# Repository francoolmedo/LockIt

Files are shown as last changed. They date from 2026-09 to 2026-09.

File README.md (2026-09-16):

<div align="center">

# 🔐 LockIt

**Lockers inteligentes que se abren con un toque.**
Sin llaves, sin candados, sin fichas. Acercás tu celu al tag NFC y tu locker se abre.

*Córdoba, Argentina* · Producto físico + IoT + Web

</div>

---

## ¿Qué es LockIt?

LockIt es un sistema de **casilleros inteligentes** pensado para gimnasios, coworkings,
clubes, escuelas de danza/música, oficinas y aeropuertos. Cada locker se desbloquea
acercando el celular a un **tag NFC** pegado en la puerta, que abre una **webapp rápida**
y linda; la cerradura se libera sola. Un **sensor magnético** confirma si la puerta quedó
bien cerrada, y todos los lockers se comunican **en malla** por el WiFi del local para
mostrar, en conjunto, cuáles están libres y cuáles ocupados.

### El problema que resuelve
- **Llaves y fichas que se pierden**, se roban o hay que reponer.
- **No saber qué locker está libre** sin ir probando puerta por puerta.
- **Candados propios** que el local no controla ni puede liberar.
- Una experiencia **anticuada** en lugares que quieren verse modernos.

### La propuesta
- 📱 **Apertura con NFC**: acercás el celu, se abre. Cero fricción, cero app para instalar.
- 👀 **Estado visible**: dos líneas de producto —
  - **LockIt Clear** → puerta transparente (ves si hay algo adentro) + aro LED de estado.
  - **LockIt Glow** → puerta opaca + aro LED de color "fachero".
- 🕸️ **Red en malla**: los lockers se hablan entre sí y con un panel central.
- 🔒 **Confirmación real de cierre**: sensor de efecto Hall + imán detecta puerta cerrada.
- 🧰 **Control del local**: panel para asignar, liberar, ver ocupación y cobrar por uso.

---

## Estructura del repositorio

Este repo es un **monorepo** que contiene todo el proyecto: producto físico, electrónica,
firmware, software y go-to-market.

| Carpeta | Qué hay |
|---|---|
| [`docs/`](docs/) | Visión, **arquitectura técnica**, diseño industrial, fabricación en Córdoba, modelo de negocio y roadmap. |
| [`hardware/`](hardware/) | **BOM** (lista de materiales con costos), esquemático de conexiones y **firmware** del ESP32. |
| [`cad/`](cad/) | Modelo **CAD paramétrico** del locker (por código, exporta STEP/STL/DXF) y planos. |
| [`webapp/`](webapp/) | La **webapp** que se abre al escanear el NFC (prototipo funcional). |
| [`panel/`](panel/) | **Panel del local** (demo): ocupación en vivo, asignar/liberar/abrir. |
| [`landing/`](landing/) | **Landing page** animada para vender el producto. |
| [`marketing/`](marketing/) | Estrategia, copies de redes, guion de animación y outreach a empresas. |
| [`brand/`](brand/) | Identidad de marca (nombre, tono, paleta, dirección de logo). |

### Por dónde empezar a leer
1. [`docs/01-vision-y-producto.md`](docs/01-vision-y-producto.md) — qué construimos y para quién.
2. [`docs/02-arquitectura-tecnica.md`](docs/02-arquitectura-tecnica.md) — **cómo funciona todo el sistema**.
3. [`docs/06-roadmap.md`](docs/06-roadmap.md) — el camino de prototipo → piloto → producción.

---

## Estado del proyecto

🌱 **Etapa 1 — Fundación** (actual). Se define el producto, la arquitectura, el CAD, la
landing y el go-to-market. Todavía **no hay prototipo físico armado**.

Ver el detalle de etapas en [`docs/06-roadmap.md`](docs/06-roadmap.md).

---

## Líneas de producto

| | **LockIt Clear** | **LockIt Glow** |
|---|---|---|
| Puerta | Transparente (policarbonato/acrílico) | Opaca (melamina/chapa) |
| Estado | Se ve el interior + aro LED | Aro LED de color en la puerta |
| Ideal para | Gimnasios, clubes, escuelas | Oficinas, coworkings, uso premium |
| Costo relativo | Menor | Mayor (más electrónica) |

---

## Licencia

Ver [`LICENSE`](LICENSE).

> ⚠️ Este README y los documentos del repo son material de trabajo interno del proyecto.
> Precios, proveedores y especificaciones son estimaciones a validar en Córdoba.

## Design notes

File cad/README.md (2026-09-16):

# CAD — Modelo paramétrico del locker

CAD **por código** con [CadQuery](https://cadquery.readthedocs.io). Cambiás las medidas en
un archivo de parámetros y se regenera todo el modelo y los archivos para el taller.

## Requisitos

```bash
pip install cadquery        # probado con cadquery 2.8.0 / Python 3.11
```

## Uso

```bash
cd cad
python build.py             # exporta AMBAS variantes (clear + glow) a exports/
python build.py clear       # solo LockIt Clear
python build.py glow column # LockIt Glow + una columna de N módulos apilados
```

## Archivos

| Archivo | Qué es |
|---|---|
| `lockit_params.py` | **Todas las medidas** (mm). Única fuente de verdad. Editá acá. |
| `lockit_module.py` | Modelo: `build_body`, `build_door`, `build_assembly`, `build_column`, `door_profile_2d`. |
| `build.py` | Genera los archivos de fabricación en `exports/`. |
| `exports/` | Salida (STEP/STL/DXF/SVG). No se versiona el binario pesado; se regenera. |

## Qué genera (`exports/`)

Por cada variante (`clear`, `glow`):

| Salida | Para qué sirve |
|---|---|
| `..._gabinete.step` / `.stl` | Gabinete 3D. STEP = para el taller / otro CAD (Fusion, SolidWorks). STL = impresión 3D / preview. |
| `..._puerta.step` / `.stl` | Puerta 3D (ventana transparente en Clear o rebaje del aro LED en Glow). |
| `..._modulo.step` / `.stl` | **Ensamble completo** (gabinete + puerta + policarbonato en Clear), coloreado. |
| `..._puerta_corte2d.dxf` | **Plano de corte 2D** (contorno + calados) para láser/router CNC. Lo que va al taller. |
| `..._puerta_corte2d.svg` | Vista rápida del plano de corte. |
| `..._gabinete_iso.svg` | Vista previa isométrica del gabinete. |

## Medidas actuales (módulo de gimnasio)

- **Interior útil:** 300 × 400 × 450 mm (ancho × alto × prof) — entra mochila de gym, toalla, botella.
- **Exterior del módulo:** ~330 × 430 × 465 mm.
- **Columna de 4 puertas:** ~1.845 mm de alto (con base y tapa).
- **Material base:** panel de 15 mm (melamina resistente a humedad / chapa plegada equivalente).
- **Puerta:** 12 mm. Clear = policarbonato/acrílico con marco; Glow = opaca con rebaje para el aro LED.

> Ver el criterio de estas medidas y materiales en
> [`../docs/03-diseno-industrial.md`](../docs/03-diseno-industrial.md).

## Notas de diseño

- Es un modelo de **intención de diseño** para prototipo y cotización, no un plano de
  producción final. Espesores, holguras de puerta y herrajes se ajustan al material y a la
  máquina reales del taller en la Etapa 2.
- El alojamiento de cerradura + ESP32 está modelado como rebaje interno del lado opuesto a
  la bisagra (ver `_cut_lockbox`).
- La ventilación trasera evita olor/humedad (clave en gimnasios).
- Para pasar de melamina a **chapa plegada** se reusa la misma geometría: el `wall` pasa a
  representar el plegado y se generan los desarrollos de chapa (mejora futura del `build.py`).

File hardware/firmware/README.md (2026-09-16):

# Firmware · Nodo LockIt (ESP32)

Firmware del **nodo** de cada puerta. Un nodo puede correr en dos roles:
- **NODO**: controla su cerradura, lee el sensor de puerta, muestra estado, habla por ESP-NOW.
- **GATEWAY**: además, se conecta al WiFi del local y hace de puente con la nube (MQTT).

## Toolchain

Recomendado **PlatformIO** (VS Code) por manejo de librerías y multi-target. Alternativa:
Arduino IDE.

```ini
; platformio.ini (ejemplo)
[env:lockit_node]
platform = espressif32
board = esp32dev
framework = arduino
monitor_speed = 115200
lib_deps =
    ; fastled/FastLED               ; aro LED WS2812 (Clear y Glow)
    ; knolleary/PubSubClient        ; MQTT (solo gateway)
```

## Estructura

```
lockit_node/
├── config.h          # pines, rol, red, tiempos — TODO lo configurable
├── lockit_node.ino   # setup/loop + máquina de estados del locker
```

> Es un **esqueleto** para arrancar el prototipo: define la máquina de estados, el control de
> cerradura por pulso, la lectura del sensor Hall y los stubs de ESP-NOW/MQTT. La lógica de
> red real (emparejar peers ESP-NOW, protocolo de mensajes, MQTT topics) se completa en la
> Etapa 2 al armar el primer nodo físico.

## Máquina de estados del locker

```
LIBRE ──(reserva desde app)──> RESERVADO
RESERVADO ──(comando abrir)──> ABRIENDO ──(pulso cerradura)──> ABIERTO
ABIERTO ──(sensor: puerta cerrada)──> OCUPADO
OCUPADO ──(dueño abre de nuevo)──> ABIERTO
OCUPADO ──(liberar / fin sesión)──> LIBRE
```

## Protocolo ESP-NOW (borrador)

Mensajes cortos entre gateway y nodos:

| Tipo | Dirección | Payload |
|---|---|---|
| `OPEN` | gateway → nodo | id_locker |
| `STATE` | nodo → gateway | id_locker, estado, puerta(abierta/cerrada), rssi |
| `PING`/`PONG` | ambos | keepalive de malla |
| `ASSIGN` | gateway → nodo | id_locker ← sesión/usuario |

Se cifra con clave pre-compartida (PMK/LMK de ESP-NOW). Detalle de seguridad en
[`../../docs/02-arquitectura-tecnica.md`](../../docs/02-arquitectura-tecnica.md#8-seguridad-y-privacidad).

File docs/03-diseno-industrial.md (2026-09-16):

# 03 · Diseño Industrial

> Cómo se ve, se siente y se arma el locker. El objetivo: que **no parezca una caja de
> metal industrial**, sino un producto de diseño con carácter, y que a la vez sea
> **fabricable en Córdoba** y aguante el uso real de un gimnasio.

El modelo CAD paramétrico que materializa todo esto está en [`../cad/`](../cad/).

---

## Concepto de diseño

**"Confianza a la vista."** El locker comunica su estado sin que tengas que tocarlo: o ves
adentro (Clear) o te lo dice con luz (Glow). Líneas limpias, aristas suavemente redondeadas,
un punto de color (verde LockIt) como firma. Nada de bisagras a la vista ni candados
colgando.

- **Carácter, no ruido:** superficies mate, un solo acento de color, tipografía/numeración
  clara en cada puerta.
- **Modular y apilable:** se venden **columnas** de N puertas; el local arma su pared.
- **Antivandálico y anti-humedad:** pensado para vestuario de gym (sudor, agua, golpes).

---

## Dimensiones (módulo de gimnasio)

| Medida | Valor | Por qué |
|---|---|---|
| Interior útil | **300 × 400 × 450 mm** (an × al × prof) | Entra mochila de gym, toalla, botella, zapatillas. |
| Exterior módulo | ~330 × 430 × 465 mm | Con paredes de 15 mm. |
| Puertas por columna | 4 (config.) | Altura de columna cómoda (~1.85 m). |
| Altura de columna | ~1.845 mm | Todo alcanzable sin escalera. |
| Puerta | 12 mm | Rígida sin ser pesada. |

> Variante **Large** (mochilas grandes / cascos / aeropuerto): 350 × 550 × 500 mm, 3 puertas
> por columna. Definida en `cad/lockit_params.py` como `GYM_LARGE_CLEAR`.

---

## Materiales

### Estructura (gabinete)
| Opción | Pro | Contra | Uso |
|---|---|---|---|
| **Melamina 15 mm hidrófuga** | Barata, se corta/arma local, muchos colores | Menos resistente al agua extrema | ✅ Prototipo y gimnasios estándar |
| **Chapa plegada (acero pintado)** | Muy robusta, antivandálica | Más cara, requiere plegado/pintura | Ambientes duros / premium |
| **Compact/HPL fenólico** | Impermeable, ideal vestuario húmedo | El más caro | Spa, natatorios, premium |

### Puerta
- **Clear:** **policarbonato** (resistente a impacto, no astilla) o **acrílico** (más barato,
  se raya más). Recomendado policarbonato para uso intenso.
- **Glow:** melamina/MDF laminado o chapa, con **rebaje circular** para el aro LED.

### Herrajes
- Bisagras ocultas o de piano (según variante y presupuesto).
- Cerradura solenoide 12 V embutida (ver [hardware](../hardware/)).
- Patas/zócalo niveladores en la base de la columna.

---

## "Chiches" y detalles (lo que da carácter)

1. **Aro LED de estado** (Clear y Glow): verde = libre, ámbar = reservado, azul = ocupado,
   animación suave = abriendo. Se lee de lejos en todo el vestuario.
2. **Aro embutido a ras** (Glow): mismo aro sobre puerta opaca, con rebaje circular prolijo.
   Es el "wow", sin pantalla que envejezca.
3. **Numeración grande y legible** grabada/impresa en cada puerta.
4. **Rebaje de agarre** (sin manija que enganche ni se rompa) — modelado en el CAD.
5. **Ventilación trasera** discreta (ranuras) para que no junte olor/humedad.
6. **Zona NFC señalizada**: un círculo/ícono impreso donde apoyar el celu (UX física).
7. **Base con luz indirecta** opcional (línea LED al piso) para look premium.

---

## Ergonomía y accesibilidad

- Puertas y tags a altura alcanzable (evitar la fila más alta > 1.7 m para NFC).
- Al menos una columna con módulos a **altura accesible** (silla de ruedas) por instalación.
- Apertura que no invada el pasillo (puerta ~90°, o corredera en espacios chicos — variante futura).

---

## Acabados y color

- **Cuerpo:** grafito mate (firma LockIt) o blanco/gris para ambientes claros.
- **Acento:** verde LockIt en LED, detalles y numeración.
- **Personalización por cliente:** color de cuerpo y branding del gym en la puerta (upsell).

---

## De diseño a fabricación

El CAD paramétrico ([`../cad/`](../cad/)) exporta:
- **STEP/STL** del gabinete, puerta y ensamble → para el taller y para visualizar/renderizar.
- **DXF de corte 2D** de la puerta (contorno + calados) → directo a láser/router CNC.

El detalle de cómo mandarlo a fabricar en Córdoba y la plantilla de cotización están en
[`04-fabricacion-cordoba.md`](04-fabricacion-cordoba.md).

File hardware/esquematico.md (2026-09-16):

# Hardware · Esquemático de conexiones (nodo)

Diagrama de conexiones de **un nodo** (ESP32 + cerradura + sensor de puerta + indicador).
Pines de referencia para ESP32 WROOM-32 (ajustar en el firmware `config.h`).

## Diagrama de bloques

```mermaid
flowchart LR
    PSU[Fuente 12V] --> BUCK[Buck 12V→3.3V]
    PSU -->|12V| LOCKPWR[Cerradura 12V]
    BUCK -->|3.3V| ESP[ESP32]

    ESP -->|GPIO -> gate| MOSFET[MOSFET IRLZ44N]
    MOSFET -->|conmuta GND| LOCKPWR
    LOCKPWR -.diodo flyback.- MOSFET

    HALL[Sensor Hall A3144] -->|GPIO in| ESP
    MAG[Imán en la puerta] -.campo.- HALL

    ESP -->|GPIO data| RING[Aro LED WS2812 - Clear y Glow]

    NFC[Tag NFC pasivo en la puerta] -.lo lee el celular.- PHONE[📱]
```

> En la variante **base**, el NFC es un **tag pasivo** que lee el celular; el ESP32 **no**
> tiene lector. En la variante **Pro**, se agrega un lector PN532 por I2C/SPI al ESP32.

## Tabla de pines (referencia, ESP32 WROOM-32)

| Señal | Pin ESP32 | Notas |
|---|---|---|
| Cerradura (gate MOSFET) | GPIO 25 | Pulso 150–250 ms para abrir. Resistencia 100 Ω en gate, pulldown 10 kΩ. |
| Sensor Hall (puerta) | GPIO 34 (input only) | Pull-up; LOW/HIGH = cerrada/abierta (según imán). |
| Aro LED estado (Clear y Glow) | GPIO 26 | Data de WS2812 (aro direccionable). |
| Lector NFC PN532 (Pro) | GPIO 21/22 (I2C) o SPI | Solo variante Pro. |
| Alimentación lógica | 3V3 / GND | Desde buck converter. |

## Circuito de la cerradura (lo más delicado)

```
                +12V
                 │
              [Cerradura solenoide]
                 │
                 ├───────┐
                 │      ─┴─  Diodo flyback (1N4007) — cátodo a +12V
                 │      ───
                 │       │
              Drain      │
   GPIO25 ──[100Ω]── Gate  IRLZ44N (MOSFET N-channel, logic-level)
                    Source
                 │
                [10kΩ] pulldown a GND
                 │
                GND (común con ESP32)
```

**Reglas:**
1. **Masa común** entre 12 V y ESP32 (imprescindible).
2. **Diodo flyback** en antiparalelo a la cerradura (protege del pico inductivo al cortar).
3. MOSFET **logic-level** (IRLZ44N conmuta bien con 3.3 V; un IRF540 común NO).
4. Pulso corto para abrir; nunca dejar la cerradura energizada.

## Alimentación de una columna

```
Fuente 12V 5A ──┬── Nodo 1 (buck → ESP32 + cerradura)
                ├── Nodo 2
                ├── Nodo 3
                └── Nodo 4
```

Una fuente 12 V por columna alimenta todos los nodos (cada uno con su buck para la lógica).
Dimensionar la fuente por el **pico simultáneo** de cerraduras (peor caso: varias abriendo a
la vez → en la práctica se abren de a una, pero dejar margen).

## Seguridad eléctrica

- Fusible en la entrada de 12 V.
- Bornera con protección; cableado prolijo dentro de canaleta.
- En instalación final, certificar según normativa (ver
  [`../docs/04-fabricacion-cordoba.md`](../docs/04-fabricacion-cordoba.md)).

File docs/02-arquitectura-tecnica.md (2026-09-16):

# 02 · Arquitectura Técnica

> Este es el documento central de ingeniería. Describe **cómo funciona todo el sistema**,
> de la punta del celular al fierro de la cerradura. Cada decisión trae su alternativa y el
> porqué, para que sea discutible y quede registrado.

---

## 1. Vista general del sistema

LockIt tiene cuatro capas:

```mermaid
flowchart TB
    subgraph Usuario
        P[📱 Celular del usuario]
    end
    subgraph Local["Local (gimnasio, WiFi propio)"]
        subgraph Malla["Malla de lockers (ESP-NOW)"]
            N1[Nodo locker 1<br/>ESP32]
            N2[Nodo locker 2<br/>ESP32]
            N3[Nodo locker N<br/>ESP32]
        end
        GW[🛰️ Gateway<br/>ESP32 + WiFi del local]
        N1 --- GW
        N2 --- GW
        N3 --- GW
    end
    subgraph Nube["Nube (hosteado)"]
        API[API + Base de datos]
        WEB[🌐 WebApp NFC / PWA]
        PANEL[🖥️ Panel del local]
    end

    P -- "1. escanea tag NFC (URL)" --> WEB
    WEB -- "2. pide abrir locker X" --> API
    API -- "3. orden de apertura" --> GW
    GW -- "4. ESP-NOW: abrí X" --> N1
    N1 -- "5. libera cerradura + confirma con sensor" --> GW
    GW -- "6. estado real" --> API
    API --> PANEL
```

**Resumen del flujo feliz:** el usuario acerca el celu al tag NFC → se abre la webapp →
identifica el locker → pide apertura → la nube manda la orden al gateway → el gateway se la
pasa por malla al nodo del locker → el nodo libera la cerradura y confirma con el sensor
magnético que la puerta se abrió/cerró → el estado sube a la nube y se refleja en el panel.

---

## 2. El nodo del locker (hardware por puerta)

Cada puerta es un **nodo** autónomo con un ESP32. Detalle de componentes y costos en
[`hardware/BOM.md`](../hardware/BOM.md); conexiones en
[`hardware/esquematico.md`](../hardware/esquematico.md).

| Componente | Función | Notas |
|---|---|---|
| **ESP32** (WROOM-32 / C3) | Cerebro del nodo | WiFi + BLE + ESP-NOW. El C3 es más barato; el WROOM tiene más pines. |
| **Cerradura electromecánica 12 V** | Traba física | Solenoide (pestillo) o electroimán. Elegimos **solenoide tipo "cabinet lock"** (consume solo al abrir). |
| **Driver MOSFET / módulo relé** | Maneja los 12 V de la cerradura desde un pin de 3.3 V | MOSFET (ej. IRLZ44N) mejor que relé: silencioso, rápido, sin desgaste. Diodo flyback obligatorio. |
| **Sensor de efecto Hall + imán** | Confirma puerta **cerrada/abierta** | Imán en la puerta, sensor en el marco. Alternativa: reed switch (más barato, menos robusto). |
| **Lector NFC PN532** (opcional en el nodo) | Ver nota abajo sobre dónde va el NFC | En el modelo base el "NFC" es un **tag pasivo** en la puerta, no un lector. |
| **Indicador de estado** | **Aro LED direccionable WS2812** (Clear y Glow) | Verde=libre, ámbar=reservado, azul=ocupado; animación suave al abrir. |
| **Alimentación** | 12 V para cerradura, 3.3 V para ESP32 (buck converter) | Una fuente por columna alimenta a todos los nodos. |

### 2.1 ¿Lector NFC o tag NFC? — Decisión clave

Hay dos arquitecturas posibles para el "NFC en la puerta". Franco describió que el tag
**abre una webapp**, así que la arquitectura base es la **(A)**:

- **(A) Tag NFC pasivo (recomendada, base).** En la puerta va una **etiqueta NFC pasiva**
  (NTAG213/215, centavos) grabada con un registro **NDEF = una URL**, por ejemplo
  `https://app.lockit.ar/l/GYM01-014`. El celular la lee **nativamente** (sin app: Android e
  iOS abren URLs de tags NFC), se abre la PWA y el locker se identifica solo por la URL. **El
  nodo no necesita lector NFC** → mucho más barato y simple. La "inteligencia" de abrir está
  en la webapp + la nube + el ESP32.
- **(B) Lector NFC activo en el nodo.** El nodo lleva un **PN532** y el usuario apoya una
  tarjeta/llavero NFC propio. Sirve para **modo sin celular** (socios con credencial) o
  **modo offline** (abre sin internet validando la tarjeta localmente). Es más caro (~USD 4–8
  por puerta) pero da robustez.

**Plan:** arrancamos con (A) para el prototipo y el piloto. Dejamos (B) como **opción de
nodo "Pro"** para clientes que quieran credencial física o apertura offline garantizada.

---

## 3. Red: cómo se comunican los lockers

### 3.1 Topología elegida: malla ESP-NOW + un Gateway al WiFi

- Los nodos se hablan entre sí con **ESP-NOW** (protocolo de Espressif, sin router, bajo
  consumo, muy confiable en distancias cortas). Forman una **malla** liviana.
- **Un nodo hace de Gateway**: además de ESP-NOW, se conecta al **WiFi del local** y es el
  único que habla con la nube. Recibe órdenes de la API y las reparte por la malla; junta el
  estado de todos y lo sube.

```mermaid
flowchart LR
    Cloud[(☁️ Nube/API)]
    GW[🛰️ Gateway<br/>WiFi + ESP-NOW]
    Cloud <-->|WiFi del local| GW
    GW <-->|ESP-NOW| A[Nodo A]
    GW <-->|ESP-NOW| B[Nodo B]
    A <-->|ESP-NOW| C[Nodo C]
    B <-->|ESP-NOW| D[Nodo D]
```

**Por qué así (trade-offs):**

| Opción | Pro | Contra | Veredicto |
|---|---|---|---|
| **A) Todos al WiFi del local (estrella)** | Simple de programar | Depende 100% del WiFi del gym (que suele ser malo/saturado); satura el AP con N clientes | ❌ Frágil |
| **B) Malla ESP-NOW + 1 Gateway** ✅ | Solo 1 dispositivo usa el WiFi; malla robusta; funciona aunque el WiFi ande mal | Hay que manejar el ruteo simple y el rol de gateway | ✅ **Elegida** |
| C) painlessMesh (malla sobre WiFi) | Malla "real" con IP | Más pesado, más consumo, más inestable con muchos nodos | 🔸 Alternativa si ESP-NOW queda corto |
| D) LoRa / RS-485 cableado | Muy robusto/largo alcance | Cableado (RS-485) o licencias/costo (LoRa); over-engineering para un gym | 🔸 Solo para instalaciones grandes/distribuidas |

> **Regla práctica:** ESP-NOW anda excelente hasta decenas de nodos en el radio de un local.
> Si un cliente tiene cientos de puertas en varias salas, se ponen **varios gateways** por
> zona, cada uno con su sub-malla.

### 3.2 Redundancia del gateway
El rol de gateway se puede **elegir por software**: si el gateway se cae, otro nodo con
credenciales de WiFi asume el rol (elección por menor MAC, por ejemplo). Se documenta como
mejora post-piloto.

---

## 4. Flujo de desbloqueo, paso a paso

```mermaid
sequenceDiagram
    actor U as 📱 Usuario
    participant Tag as 🏷️ Tag NFC (puerta)
    participant Web as 🌐 WebApp (PWA)
    participant API as ☁️ API
    participant GW as 🛰️ Gateway
    participant Node as 🔒 Nodo locker

    U->>Tag: Acerca el celular
    Tag-->>U: URL https://app.lockit.ar/l/GYM01-014
    U->>Web: Abre la URL (navegador nativo)
    Web->>API: GET estado del locker 014 (+ token de sesión)
    API-->>Web: libre / ocupado / tuyo
    Note over Web,API: Validación "misma red" (ver §5)
    U->>Web: Toca "Abrir"
    Web->>API: POST abrir(GYM01-014)
    API->>GW: comando abrir(014) [MQTT/WebSocket]
    GW->>Node: ESP-NOW: abrir(014)
    Node->>Node: activa cerradura 200 ms
    Node->>Node: lee sensor Hall (¿puerta se abrió?)
    Node-->>GW: ack + estado real
    GW-->>API: estado(014) = abierto
    API-->>Web: ✅ abierto
    Web-->>U: Animación "¡Locker abierto!"
```

### Estados de un locker
`LIBRE → RESERVADO(tuyo) → ABIERTO → OCUPADO(cerrado con cosas) → LIBRE (al liberar)`

El **sensor Hall** es lo que distingue "cerrado" de "abierto" de verdad, y evita que el
sistema crea que está ocupado cuando la puerta quedó entornada.

---

## 5. Validación "misma red WiFi" — cómo lo hacemos bien

Franco pidió que la webapp **detecte que está en el mismo WiFi** que los lockers. Un
navegador **no puede leer el SSID del WiFi** por seguridad, así que lo resolvemos de forma
robusta. Opciones reales:

| Método | Cómo | Robustez | Uso |
|---|---|---|---|
| **URL firmada + estar presente físicamente** | El tag solo se puede escanear estando al lado del locker; la URL lleva el id + firma corta | Alta (requiere presencia física) | ✅ Base — el NFC ya prueba presencia |
| **Handshake local (mDNS/IP privada)** | La PWA intenta hablar con el gateway en la LAN (`http://lockit.local`) | Media (CORS/HTTPS mixto complica) | 🔸 Refuerzo opcional |
| **Token de sesión por tiempo** | Al escanear, la API abre una ventana de N minutos para ese locker/usuario | Alta | ✅ Base |
| **Chequeo de IP pública** | La API compara la IP pública del celu con la registrada del gateway del local | Media (WiFi del gym = misma IP saliente) | ✅ Refuerzo simple y efectivo |

**Diseño elegido (defensa en capas):**
1. El **tag NFC prueba presencia física** (estás parado frente al locker).
2. La **API abre una ventana de tiempo** (ej. 90 s) para operar ese locker.
3. La API **compara la IP pública** del celular con la del gateway del local → si coincide,
   está en la misma red del gym (refuerzo, no único). Si el celu está en datos móviles y no
   en el WiFi, se puede pedir un paso extra o igual permitir (configurable por local).

> Así no dependemos de que el navegador "vea el WiFi" (imposible), sino de pruebas reales:
> presencia física (NFC) + ventana temporal + coincidencia de red. Simple y difícil de abusar.

---

## 6. Modo degradado (sin internet)

El WiFi del gym **se va a caer** alguna vez. LockIt no puede dejar a nadie encerrado sin sus
cosas. Estrategias, de menor a mayor costo:

1. **Cache de sesiones en el gateway**: el gateway guarda las reservas activas; si se cae
   internet pero él sigue, resuelve aperturas localmente por un rato.
2. **Apertura por credencial física** (nodo "Pro" con lector NFC, opción B de §2.1):
   funciona 100% offline validando la tarjeta contra una lista local.
3. **Botón/llave maestra de emergencia** por columna para el staff (mecánico, siempre
   funciona aunque se corte la luz).
4. **Falla en seguro configurable**: por política del local, ante corte total la cerradura
   puede quedar **normalmente cerrada** (seguridad) o **liberarse** (que la gente saque sus
   cosas). Recomendado para gimnasios: mantener cerrado + llave maestra del staff.

---

## 7. Software: nube, webapp y panel

```mermaid
flowchart LR
    subgraph Front
      WEB[WebApp NFC - PWA]
      PANEL[Panel del local]
    end
    subgraph Back["Backend (hosteado)"]
      API[API REST/WebSocket]
      DB[(Base de datos)]
      MQ[Broker MQTT]
    end
    WEB <--> API
    PANEL <--> API
    API <--> DB
    API <--> MQ
    MQ <--> GW[Gateways de los locales]
```

- **WebApp NFC (PWA)** — [`../webapp/`](../webapp/): lo que ve el usuario al escanear.
  Rápida, sin instalación, con la marca. Prototipo mock ya incluido en el repo.
- **Panel del local**: ocupación en vivo, asignar/liberar, historial, cobros. (Etapa posterior.)
- **API + DB**: usuarios/sesiones, lockers, locales, eventos. Stack sugerido: Node/TS o
  Python (FastAPI) + Postgres. **A definir en Etapa 2.**
- **MQTT** entre la nube y los gateways: liviano, ideal para IoT, reconexión robusta.

---

## 8. Seguridad y privacidad

- **Tags NFC firmados**: la URL incluye una firma corta para que no se puedan clonar
  arbitrariamente lockers falsos. (NTAG con protección de escritura.)
- **Sesión por tiempo y por usuario**: un locker "tuyo" solo lo abrís vos dentro de la ventana.
- **Comunicación cifrada**: TLS entre PWA/panel y API; ESP-NOW con clave pre-compartida (PMK/LMK).
- **Mínimos datos personales**: se puede usar anónimo (solo id de sesión) o con cuenta según el local.
- **Antiabuso**: rate limiting en apertura; log de todos los eventos para auditoría del local.

---

## 9. Decisiones abiertas (a cerrar en Etapa 2)

- [ ] Cerradura definitiva: solenoide vs electroimán (probar consumo, ruido, robustez).
- [ ] ESP32 WROOM-32 vs C3 (pines vs costo) — decidir tras armar el primer nodo.
- [ ] Stack de backend (Node/TS vs Python/FastAPI) y hosting (Vercel/Fly/Railway/VPS).
- [ ] ¿Nodo base (solo tag) o nodo Pro (lector NFC) para el piloto? — depende del gym piloto.
- [ ] Sensor de puerta: Hall (robusto) vs reed switch (barato) — validar en prototipo.

Ver el plan de validación en [`06-roadmap.md`](06-roadmap.md).

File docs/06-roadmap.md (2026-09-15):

# 06 · Roadmap

> El camino de idea → producto → negocio, por etapas. Cada etapa tiene un objetivo claro y un
> "listo cuando…". Pensado para avanzar con poco capital y validar rápido.

---

## Etapa 0 · Fundación ✅ (actual)

**Objetivo:** definir el producto y dejar todo documentado y diseñado.

- [x] Visión, producto y dos líneas (Clear / Glow).
- [x] Arquitectura técnica completa (ESP32, malla, NFC, sensor, seguridad).
- [x] CAD paramétrico + archivos de fabricación (STEP/STL/DXF).
- [x] BOM, esquemático y esqueleto de firmware.
- [x] Identidad de marca (logo, paleta, tipografía, motion).
- [x] Landing con 3D en vivo + webapp NFC (mock).
- [ ] Estrategia de marketing y borradores de outreach (en curso).

**Listo cuando:** el repo cuenta la historia completa y se puede mostrar a un socio/proveedor.

---

## Etapa 1 · Prototipo funcional (1 nodo)

**Objetivo:** que **una puerta** abra de verdad con NFC.

- [ ] Comprar electrónica de 1 nodo ([BOM](../hardware/BOM.md)).
- [ ] Armar el circuito (cerradura + MOSFET + sensor Hall) en protoboard.
- [ ] Firmware: apertura por pulso + lectura de sensor + máquina de estados.
- [ ] Tag NFC → webapp → "abrir" (aunque sea contra un servidor local).
- [ ] Fabricar **1 gabinete** (melamina) para montar el nodo.

**Listo cuando:** acercás el celu, se abre la cerradura y el sensor confirma el cierre.
**Costo estimado:** bajo (~USD 30–60 electrónica + 1 gabinete).

---

## Etapa 2 · Columna piloto (4 puertas + red)

**Objetivo:** una **columna completa** con malla y panel.

- [ ] 4 nodos + 1 gateway hablando por ESP-NOW.
- [ ] Backend mínimo (API + estado + MQTT) hosteado.
- [ ] Webapp NFC real (asignación, sesión, abrir/liberar).
- [ ] Panel del local (ocupación en vivo, asignar/liberar).
- [ ] Modo degradado sin internet.
- [ ] Cotizar y fabricar la columna (melamina) en Córdoba.

**Listo cuando:** una columna de 4 puertas funciona sola, con panel y sin depender de una PC.

---

## Etapa 3 · Piloto en un gimnasio real

**Objetivo:** validar con usuarios reales y sacar el caso de éxito.

- [ ] Instalar 1–2 columnas en un gimnasio de Córdoba.
- [ ] Medir: tiempo de apertura, tasa de éxito, uso por puerta, incidencias.
- [ ] Iterar UX física (dónde va el tag, luz, etc.) y firmware.
- [ ] Juntar **testimonio + video real** para vender.

**Listo cuando:** el gimnasio lo usa a diario sin que tengas que estar ahí, y tenés métricas + video.

---

## Etapa 4 · Producto y primeras ventas

**Objetivo:** estandarizar y vender a más locales.

- [ ] Congelar diseño "v1" (estructura, electrónica, instalación).
- [ ] Cotizar **serie** (chapa o melamina) para bajar costo por puerta.
- [ ] Precio y contrato (hardware + suscripción, ver [negocio](05-modelo-negocio.md)).
- [ ] Vender a 3–5 gimnasios de Córdoba (outreach + boca a boca).
- [ ] Red mínima de instalación/soporte.

**Listo cuando:** hay clientes pagando y un proceso repetible de venta e instalación.

---

## Etapa 5 · Escala y nuevos segmentos

**Objetivo:** crecer más allá de gimnasios de Córdoba.

- [ ] Coworkings, clubes, escuelas de danza/música.
- [ ] Features premium (cobro por uso, reportes, integraciones).
- [ ] Variante aeropuerto/público (pago por uso, más seguridad).
- [ ] Expandir a otras ciudades / cadenas.

---

## Vista rápida

```mermaid
flowchart LR
    E0[0 · Fundación ✅] --> E1[1 · 1 nodo abre]
    E1 --> E2[2 · Columna + red + panel]
    E2 --> E3[3 · Piloto en gym real]
    E3 --> E4[4 · Producto + ventas]
    E4 --> E5[5 · Escala y segmentos]
```

> **Principio:** cada etapa cuesta poco y prueba algo. No fabricar 50 columnas antes de que
> **una** puerta funcione y **un** gimnasio la use.

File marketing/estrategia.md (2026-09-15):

# Marketing · Estrategia

> Cómo damos a conocer LockIt y conseguimos los primeros clientes, con poco presupuesto y
> foco en **gimnasios de Córdoba**. Usa la voz y la paleta de [`../brand/identidad.md`](../brand/identidad.md).

---

## Posicionamiento

> **LockIt es el casillero que se abre con un toque.** Sacá las llaves, los candados y las
> fichas del medio: tus clientes acercan el celu y listo, y vos controlás todo desde un panel.

- **Categoría:** casilleros inteligentes / control de accesos para lockers.
- **Diferenciales:** NFC **sin instalar app** · malla WiFi sin cablear datos · **soporte
  local** (Córdoba) · estética con carácter · dos líneas (Clear/Glow).
- **Contra qué competimos:** candados propios, llaves/fichas, y lockers electrónicos
  importados caros y sin soporte local.

---

## Público y mensaje

| Público | Qué le duele | Mensaje |
|---|---|---|
| **Dueño/gerente de gimnasio** (decisor) | Costo de llaves, robos, imagen, quejas | "Modernizá tus lockers, sacá las llaves del medio y diferenciate." |
| Socio del gym (usuario) | Perder la llave, no saber cuál está libre | "Tu locker, un toque. Sin llaves." |
| Coworking / oficina | Seguridad, prolijidad, estética | "Casilleros premium que se abren con el celu." |

---

## Embudo

```mermaid
flowchart LR
    A[Redes / boca a boca] --> B[Landing con 3D]
    B --> C[Demo / mensaje]
    C --> D[Piloto en el local]
    D --> E[Venta + suscripción]
    E --> F[Caso de éxito] --> A
```

- **Tope:** contenido en redes (el 3D y el "wow" del tap venden solos) + outreach directo.
- **Medio:** la [landing](../landing/) explica y genera el contacto ("Pedir demo").
- **Fondo:** demo/piloto → venta. El **caso de éxito** retroalimenta todo.

---

## Canales (priorizados para Córdoba)

1. **Instagram / Reels** — el producto es muy visual (tap → se abre, el 3D). Canal #1.
2. **Boca a boca / relaciones** — el primer gimnasio suele salir de un conocido.
3. **Outreach directo** (mail/WhatsApp) a gimnasios y locales — ver [outreach](outreach-empresas.md).
4. **LinkedIn** — para coworkings, oficinas y clientes B2B más formales.
5. **TikTok** — clips cortos del "wow" y del detrás de escena (fabricación en Córdoba).

---

## Contenido que funciona

- 🎬 **El tap mágico:** primer plano de acercar el celu y la puerta abriéndose.
- 🧩 **El 3D que se arma/desarma** (el de la landing) — muy shareable.
- 🏗️ **Detrás de escena:** fabricación en Córdoba, prototipo, "hecho acá".
- 📊 **Antes/después:** vestuario con candados vs. con LockIt.
- 🗣️ **Testimonio** del gimnasio piloto (cuando esté).

---

## Marca en todo

- Paleta Pulso (verde) + Señal (ámbar) + Grafito. Logo con la onda de pulso.
- Tipografía Archivo + IBM Plex. Motion = "el pulso".
- Todo consistente entre landing, redes, presentaciones y producto físico.
  Ver [`../brand/identidad.md`](../brand/identidad.md).

---

## Métricas

- Alcance/guardados de los reels (señal de "wow").
- Clicks a la landing y contactos "Pedir demo".
- Demos agendadas → pilotos → ventas.
- Costo por lead y por cliente.

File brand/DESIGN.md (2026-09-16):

---
# DESIGN.md · LockIt — sistema de diseño legible por agentes
# Formato inspirado en google-labs/design.md · reglas de impeccable + taste-skill
name: LockIt
style: Premium industrial cálido — oscuro, nítido, con carácter (no genérico)
colors:
  carbon:        "#100E0B"   # fondo base (dark) — casi negro CÁLIDO, nunca #000
  carbon-2:      "#15120E"
  panel:         "#1B1710"   # superficie (dark)
  panel-light:   "#FBF7F0"   # superficie (light)
  bg-light:      "#F4EFE7"   # fondo base (light) — crema cálido
  oro:           "#E7A23C"   # MARCA / acento primario
  oro-hi:        "#F2B255"   # hover
  oro-deep:      "#B07A1E"   # oro legible sobre claro (texto/borde)
  coral:         "#F0764F"   # acento secundario cálido
  cream:         "#F3EEE6"   # texto sobre carbón
  ink:           "#211A12"   # texto sobre claro
  ink-2:         "#5A4F41"
  ink-3:         "#8A7D6B"
  line:          "#2A2418"   # hairline (dark)
  line-light:    "#E1D7C6"   # hairline (light)
  # Semánticos — SOLO estado de producto, separados del acento de marca
  st-libre:      "#3BA776"
  st-ocupado:    "#F0764F"
  st-reservado:  "#74D3F0"
typography:
  display:  { family: "Newsreader",     weights: [400, 500, 600], use: "títulos serif editorial (dirección Warm)" }
  display_alt: { family: "Archivo",     weights: [700, 800, 900], use: "alternativa sans para variantes oscuras" }
  body:     { family: "IBM Plex Sans",  weights: [400, 500, 600] }
  mono:     { family: "IBM Plex Mono",  weights: [400, 500, 600], use: "datos, IDs (dashboard); usar poco" }
rounded: { sm: "9px", md: "12px", lg: "14px", pill: "999px" }   # crisp, NO rounded-2xl en todo
spacing: { xs: "6px", sm: "10px", md: "16px", lg: "24px", xl: "40px", xxl: "80px" }
elevation:
  flat:   "none — la mayoría de las superficies (borde, no sombra)"
  raised: "0 10px 30px rgba(20,14,6,.28) — SOLO lo que debe elevarse (1 nivel, no en todo)"
components:
  button-primary: { bg: oro, text: carbon, rounded: sm, weight: 600, shadow: flat, hover: "translateY(-2px)+oro-hi" }
  button-ghost:   { bg: transparent, border: line, text: ink, hover: "border/text → oro" }
  card:           { bg: panel, border: line, rounded: md, shadow: flat, note: "NO anidar cards dentro de cards" }
# Dials (taste-skill) — la personalidad de LockIt
dials:
  variant: "warm-editorial"       # DIRECCIÓN ACTIVA: crema cálido (Aesop) + serif Newsreader + oro muteado. Ground CLARO, no oscuro
  design_variance: 7              # 1 centrado/limpio … 10 asimétrico. 7 = editorial con tensión
  motion_intensity: 4             # 1 hover … 10 scroll/magnético. Sutil, con propósito
  visual_density: 3               # 1 espacioso … 10 dashboard denso. BAJO = mucho aire
  easing: "cubic-bezier(.4,0,.2,1)"   # NUNCA bounce/elastic (se siente viejo)
---

# Sistema de diseño · LockIt

> Leer antes de diseñar cualquier pieza (web, redes, panel, decks). El front matter de arriba
> son los **tokens** (fuente de verdad, no inventar). Abajo, el criterio.
>
> **Regla madre:** buen gusto = restricción + referencias reales + un gesto propio. Si tomaste
> una decisión "porque queda bien en general", es la mediana — y la mediana es el look de IA.

## Overview
LockIt es premium industrial cálido: base carbón (casi negro con temperatura), oro como único
protagonista, coral de apoyo. Nítido, con jerarquía fuerte, y **un** gesto memorable por pieza.
Referencia de altura: Linear (oscuro nítido), Aesop (editorial cálido), Teenage Engineering
(industrial premium).

## Colors
Neutros **siempre tintados** (carbón cálido, cremas), nunca `#000`/`#fff`/gris puro. Oro con
intención (CTA, un acento por sección). Coral escaso. Estados (libre/ocupado/reservado) son
semánticos y viven aparte del acento de marca. Nunca texto gris sobre fondo de color.

## Typography
Archivo para títulos (peso alto, tracking negativo), IBM Plex Sans para cuerpo, IBM Plex Mono
para datos. Jerarquía con **contraste real** de tamaño (no todo 16–20px). Un elemento manda.

## Layout
Grid/flex con `gap`. Varianza 6: buscar asimetría/tensión, no todo centrado. Aire generoso O
densidad elegida a propósito. Gutter lateral ≥16px. Mobile-first: mirar a ~400px y arreglar.

## Elevation & Shapes
Una sola sombra, sutil, **solo** donde algo se eleva — no en cada tarjeta (aplana la jerarquía).
Radios crisp (9–14px). Bordes/hairlines antes que sombras para separar.

## Do's & Don'ts (lista negra de AI-tells)
**Hacer:** tokens de arriba · referencia real antes que descripción · un gesto distintivo por
pieza · jerarquía fuerte · pasada final de reducción (sacar el 20% que sobra).

**Nunca (tells):**
- ❌ Fuentes genéricas: Inter, Roboto, Poppins, Montserrat, Space Grotesk, system defaults.
- ❌ `#000`/gris puro; texto gris sobre fondo de color (Impeccable). Tintar siempre.
- ❌ Gradiente violeta→azul en hero; glassmorphism.
- ❌ **Anidar cards dentro de cards**; envolver todo en tarjetas (Impeccable).
- ❌ Misma sombra + mismo radio en TODOS los bloques.
- ❌ Easing **bounce/elastic** (Impeccable) — usar el `easing` del front matter.
- ❌ Barrita/rail de color al costado de tarjetas.
- ❌ Todo centrado; sin asimetría.
- ❌ Grilla de 3 "features" ícono+título+parrafito ×3.
- ❌ Emojis como íconos/bullets → íconos = SVG de línea, un solo estilo.
- ❌ Negro puro + un único pop de color; combo crema+serif+terracota.
- ⚠️ **Nuestro propio riesgo:** abusar de eyebrows mono (`§01`) + grilla de puntos + marcas de
  esquina en TODO. Dosificar; si se repite en cada bloque, vuelve a ser plantilla.

## Vocabulario de trabajo (impeccable)
Al pedir cambios, usar verbos claros: `polish` (alinear al sistema), `critique` (jerarquía/
claridad), `quieter`/`bolder` (subir/bajar intensidad), `distill` (reducir), `animate`.

## Referencias — "Editorial Locker Room" (dirección elegida)
Dirección propia, a partir de los gimnasios premium del mundo. Diseñamos sacando el lenguaje
de ESTAS (Franco puede sumar/cambiar cuando quiera):
- **Equinox** — lujo editorial: blanco/negro confiado, acero ennegrecido, piedra natural,
  campañas audaces, tipografía grande. (el "cómo comunica" premium)
- **Third Space (Londres)** — oscuro, material, wellness premium; charcoal + latón.
- **Barry's** — drama/moodiness: luz cálida sobre oscuro (tomamos la atmósfera, no el rojo).
- **Vestuario de lujo (spa 5★)** — charcoal mate + **bronce** + madera + luz por capas →
  es literalmente nuestro carbón + oro. Ese es el material de LockIt.
- Athleisure elevado (Alo / Vuori) — calma cálida, mucho aire.

Traducción a la web: charcoal + bronce, tipografía oversized, **mucho whitespace**, filas
editoriales (no cajas), reglas finas, cromo mínimo. Cero look "instrumento técnico".
Más formato en `github.com/VoltAgent/awesome-design-md`.

## Checklist antes de publicar
- [ ] Tokens del front matter (nada inventado).
- [ ] Cero ítems de la lista negra.
- [ ] Salió de una referencia real, no del genérico.
- [ ] Un gesto distintivo; el resto quieto.
- [ ] Funciona a ancho de teléfono.
- [ ] Copy pasado por [`VOICE.md`](VOICE.md).
- [ ] Pregunta final: **"¿esto lo vi mil veces?"** → si sí, cambialo.

## Herramientas vivas (opcional, para instalar)
- `npx impeccable install` — detectores de anti-patterns en tiempo real (github.com/pbakaus/impeccable).
- taste-skill (github.com/leonxlnx/taste-skill) — skills por variante (soft/minimal/brutalist).
- google-labs/design.md — CLI para validar/exportar este archivo a Tailwind / W3C tokens.

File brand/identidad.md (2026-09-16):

# Identidad de marca · LockIt

> Sistema de identidad propio y ownable, diseñado para que LockIt **no parezca genérico ni
> hecho con plantilla**. Todo —colores, logo, tipografía, botones, animaciones— sale de una
> misma idea: **el pulso del toque**, el instante en que acercás el celu y el locker se abre.

---

## Idea central

**"El pulso."** LockIt captura ese microsegundo mágico: tap → onda → clic → abierto. Esa onda
que se expande es el ADN visual de la marca: aparece en el logo, en el LED que respira, en el
hover de los botones, en la animación del 3D. Nada es decoración: todo repite el gesto del
producto.

La piel de todo eso es **premium, oscura y cálida** — inspirada en el código visual de los
smart gyms de Córdoba (negro + oro, tipo Qivox): elegante, moderno y con carácter, lejos del
look "genérico de IA".

---

## Paleta (ownable)

Nombres propios para que el equipo hable el mismo idioma. Base carbón cálido + oro como
protagonista.

| Token | Nombre | Hex (oscuro / claro) | Uso |
|---|---|---|---|
| `--carbon` | **Carbón** | `#100E0B` / `#15120E` | Fondo principal / metal del locker. Casi negro **cálido** (no teal). |
| `--panel` | Panel | `#1C1811` / `#FBF7F0` | Tarjetas y superficies. |
| `--oro` | **Oro / Ámbar** ⭐ | `#E7A23C` | **Color de marca.** CTA, acentos, logo. Cálido, premium. |
| `--oro-hi` | Oro alto | `#F2B255` | Hover / brillo. |
| `--coral` | **Coral** | `#F0764F` | Segundo acento, amigable y trendy. Energía / estado "ocupado". |
| `--crema` | Crema | `#F0E6D6` | Detalle cálido / textos sobre carbón. |
| `--ink` | Tinta | `#F3EEE6` / `#211A12` | Texto (según tema). |

**Regla de oro:** el **Oro** es la estrella y se usa con intención (CTA, estado, un detalle
por sección). El **Coral** aporta calidez/energía como segundo acento. Nunca los dos gritando
a la vez; el resto es carbón y cremas.

### Semántica de estado (parte del producto y de la marca)
- 🟡 **Oro** = Libre / abierto / disponible (glow cálido que invita).
- 🟠 **Coral** = Ocupado / en proceso / energía.
- Luz general **cálida** (no fría): el producto se ve acogedor, no de laboratorio.

---

## Logo

Marca gráfica: un **candado premium** en oro con un **marco interior grabado** que evoca la
puertita del locker (el chiche que le da personalidad), y el ojo de cerradura calado.
Significado directo: **seguridad + se abre fácil**.

- Versión completa: símbolo + wordmark "LockIt" (Archivo 800, "It" en oro, tracking ajustado).
- Isotipo (ícono/app/favicon): el candado dentro de un cuadrado redondeado carbón. El calado
  del ojo de la cerradura usa el color del fondo (se lee como hueco real).
- Construcción y SVGs de referencia: [`logo.svg`](logo.svg) e [`isotipo.svg`](isotipo.svg).
- Área de protección: el alto del cuerpo del candado alrededor del logo. No deformar, no
  rotar, no cambiar los colores fuera de las variantes definidas.

### Variantes de color del logo
- Sobre carbón: símbolo en Oro, wordmark en Crema.
- Sobre claro: símbolo en Oro, wordmark en Carbón.
- Monocromo (grabado en la puerta física): un solo tono, sin relleno de estado.

---

## Tipografía

| Rol | Familia | Uso |
|---|---|---|
| **Display** | **Archivo** (700–800) | Títulos. Industrial, ancha, con carácter de señalética/producto. |
| **Texto** | **IBM Plex Sans** (400–600) | Cuerpo. Técnica, cálida, legible. |
| **Dato/UI** | **IBM Plex Mono** (400–600) | IDs de locker (`GYM01·014`), labels, estados, specs. El toque "máquina". |

Pareja elegida a propósito para **no** caer en el default de IA (Inter / Space Grotesk).
Titulares con `text-wrap: balance`, labels en mayúscula con `letter-spacing` amplio.

---

## Motion (lenguaje de animación)

Todo se mueve con el **gesto del pulso**: una onda que se expande con easing suave
(`cubic-bezier(.4,0,.2,1)`), nunca rebotes exagerados.

- **LED / estado:** respira (opacidad + halo) en loop lento.
- **Botones:** al hover, una onda de pulso sale desde el centro; leve `translateY(-1px)`.
- **3D showcase:** al scrollear, los lockers se **desarman y arman** (exploded view) y el
  modelo rota; el scroll es el "dial" de la animación.
- **Reveal:** las secciones entran desde un estado ya visible (nunca parten de opacidad 0
  esperando scroll para poder leerse).
- Respetar siempre `prefers-reduced-motion`: sin ondas ni auto-rotación, versión estática.

---

## Voz y tono

- **Directo y argentino, sin ser grasa.** "Tu locker, un toque." "Sacá las llaves del medio."
- Técnico cuando toca (specs), humano cuando vende (beneficios).
- Los controles dicen exactamente qué pasa: botón "Abrir mi locker" → "¡Abierto!".

---

## Aplicaciones

- **Web:** landing con 3D en vivo ([`../landing/`](../landing/)) y webapp NFC ([`../webapp/`](../webapp/)).
- **Producto físico:** numeración y logo monocromo grabado en la puerta; aro LED de color con la
  semántica de estado (verde libre · ámbar reservado · azul ocupado).
- **Redes:** ver [`../marketing/`](../marketing/) (los copies y el guion usan esta voz y paleta).

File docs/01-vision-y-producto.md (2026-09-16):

# 01 · Visión y Producto

## La visión

Convertir el casillero —un objeto tonto que no cambió en 50 años— en un **punto de
contacto inteligente** entre un local y sus clientes. LockIt vende dos cosas al mismo
tiempo:

1. A la **persona que lo usa**: una experiencia mágica y sin fricción (acercás el celu, se abre).
2. Al **local que lo compra**: control, datos de uso, una nueva fuente de ingresos y una
   imagen moderna, sin tener que manejar llaves ni reponer candados.

> **Frase ancla:** *"Tu locker, un toque."*

---

## Para quién (segmentos)

Mercado **ancla: gimnasios** (donde arrancamos). Después escalamos:

| Segmento | Dolor principal | Qué valora | Modelo de cobro típico |
|---|---|---|---|
| **Gimnasios** 🏋️ (ancla) | Candados propios, robos, "¿cuál está libre?" | Higiene, rapidez, imagen premium | Incluido en cuota / venta al gym |
| Coworkings / oficinas | Asignación de casillero fijo, seguridad | Estética sobria, control de accesos | Venta o alquiler mensual |
| Clubes / danza / música | Uso por clase/evento, rotación alta | Robustez, asignación rápida | Venta al club |
| Aeropuertos / público | Anonimato, seguridad, cobro por uso | Normativa, pago integrado | Pago por uso (self-service) |

La **decisión de foco** (gimnasios) fija: tamaño de módulo mediano, materiales que aguantan
humedad y uso intenso, y un pitch centrado en higiene + imagen + cero-llaves.

---

## Propuesta de valor

### Para el usuario final
- **Cero llaves, cero fichas, cero candado propio.** Nada que perder ni cargar.
- **Apertura en 2 segundos** acercando el celular al tag NFC (no hace falta instalar app).
- **Saber al toque qué locker está libre** (puerta transparente o indicador luminoso).
- **Seguridad**: solo vos (tu sesión) abrís tu locker durante tu uso.

### Para el local (quien compra)
- **Sin gestión de llaves** ni reposición de candados perdidos.
- **Panel de control**: ver ocupación en vivo, asignar, liberar remotamente, historial.
- **Higiene e imagen**: producto lindo, moderno, que se muestra.
- **Nuevo ingreso**: cobro por uso, alquiler premium de lockers grandes, o valor agregado a la cuota.
- **Instalación simple**: se conecta al WiFi que ya tienen; los módulos se hablan en malla.

---

## Las dos líneas de producto

Decidido con el equipo: lanzamos **dos variantes** que comparten el 90% de la estructura y
la electrónica, cambiando puerta e indicador.

### 🪟 LockIt Clear
- **Puerta transparente** de policarbonato (resistente a golpes) o acrílico (más económico).
- El estado "libre/ocupado" se ve **directo** (hay o no hay cosas) y se **refuerza con un
  LED** perimetral o un punto de luz (verde = libre, azul/rojo = ocupado).
- **Ventaja**: resuelve de una el problema de "¿está usado?" y es la variante **más barata**
  (menos electrónica por puerta).
- **Ideal**: gimnasios, clubes, escuelas — donde ver el interior es un plus de confianza.

### 🌗 LockIt Glow
- **Puerta opaca** (melamina, MDF laminado o chapa plegada) para **privacidad**.
- **Aro LED direccionable (WS2812)** embutido en la puerta que muestra el estado por color
  (verde libre · ámbar reservado · azul ocupado), con animación suave al abrir.
- **Ventaja**: más "tech", más premium, más privacidad.
- **Ideal**: oficinas, coworkings, uso premium.

> Ambas variantes usan el **mismo nodo electrónico** (ESP32 + NFC + cerradura + sensor de
> puerta). La diferencia de costo está en la puerta y en el aro LED (LED puntual vs aro WS2812).

---

## Principios de diseño de producto

1. **Cero fricción para el usuario**: no instalar app, no crear cuenta obligatoria, no esperar.
2. **A prueba de local real**: humedad, golpes, uso intenso, gente apurada, poco WiFi.
3. **Falla en seguro**: si se corta internet o luz, hay un modo de apertura garantizado
   (ver [arquitectura](02-arquitectura-tecnica.md#modo-degradado-sin-internet)).
4. **Modular y apilable**: se venden columnas de N puertas; el local arma su pared.
5. **Estético con carácter**: no parece una caja de metal industrial; parece un producto
   de diseño (ver [diseño industrial](03-diseno-industrial.md)).
6. **Fabricable en Córdoba**: materiales y procesos que consigue un taller local.

---

## Qué NO es LockIt (alcance)

- No es una cerradura para puertas de casa (es para casilleros de local comercial).
- No reemplaza la seguridad de una caja fuerte (es conveniencia + control, no alta seguridad
  bancaria).
- En la Etapa 1 **no** procesa pagos reales todavía (se diseña el flujo, se implementa después).

---

## Métricas de éxito (cómo sabremos que funciona)

- ⏱️ **Tiempo de apertura** < 3 s desde que acerca el celu.
- ✅ **Tasa de apertura exitosa** > 99% (que "se abra siempre").
- 🔁 **Confiabilidad del sensor de cierre** (falsos "abierto/cerrado" < 1%).
- 😍 **NPS del usuario** en el piloto del gimnasio.
- 💵 **Costo por puerta** por debajo del objetivo del [modelo de negocio](05-modelo-negocio.md).

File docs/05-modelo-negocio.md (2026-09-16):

# 05 · Modelo de Negocio

> Cómo gana plata LockIt. Números **estimados** para ordenar la conversación y validar que el
> negocio cierra. Ajustar con cotizaciones reales ([fabricación](04-fabricacion-cordoba.md)) y
> el mercado.

---

## Modelos de ingreso (se pueden combinar)

| Modelo | Cómo | Pro | Contra |
|---|---|---|---|
| **A. Venta directa** | El local compra las columnas (CAPEX) | Ingreso grande de una; simple | Ciclo de venta más lento; el local pone la plata |
| **B. Hardware + suscripción (SaaS)** | Vende el hardware + fee mensual por el panel/soporte/nube | Ingreso recurrente (MRR); pegajoso | Requiere sostener la plataforma |
| **C. Locker-as-a-Service** | LockIt instala gratis/subsidiado y cobra por uso o revenue share | Bajísima barrera para el local | Necesita capital para financiar el hardware |
| **D. Pago por uso (público)** | En aeropuertos/públicos, el usuario paga por usar | Ingreso directo del usuario final | Requiere pasarela de pago y alto tránsito |

**Recomendado para arrancar (gimnasios):** **B — Hardware + suscripción.** Vendés/instalás
las columnas y cobrás una **mensualidad por local** (panel, actualizaciones, soporte, garantía).
Da recurrencia y te diferencia de un simple mueble.

---

## Estructura de precios (propuesta inicial, ARS/USD — validar)

### Hardware (una vez)
- **Columna de 4 puertas (Clear):** precio de venta objetivo **USD 700 – 1.000** por columna
  (según costo real ~USD 330–540 → margen bruto ~45–55%).
- **Columna Glow (aro LED):** +USD 60–120 por la puerta opaca y el aro LED direccionable.
- **Instalación y setup:** por proyecto (según cantidad de columnas).

### Suscripción (recurrente, por local)
- **Plan base:** **USD 20 – 40 / mes por local** (panel, soporte, updates).
- Escala por cantidad de puertas / features (asignación avanzada, reportes, cobro por uso).

### Ejemplo de un gimnasio tipo
- Compra 5 columnas Clear (20 puertas): 5 × USD 850 = **USD 4.250** (hardware).
- Suscripción: **USD 30 / mes** → **USD 360 / año** recurrente.

---

## Unit economics (por puerta, estimado)

| Concepto | USD |
|---|---|
| Costo hardware por puerta (estructura + electrónica, a escala) | 90 – 135 |
| Precio de venta por puerta (columna/4) | 175 – 250 |
| **Margen bruto por puerta** | **~45 – 55%** |
| + Suscripción anual prorrateada por puerta | ~4 – 8 / año recurrente |

> A escala (series de 25–50 columnas), el costo por puerta baja y el margen mejora. La
> **suscripción** es lo que convierte a LockIt de "vender muebles" a "negocio recurrente".

---

## Costos del negocio (además del hardware)

- **Desarrollo** (firmware, webapp, panel, nube) — mayor al principio, luego mantenimiento.
- **Hosting/nube** (API, MQTT, base de datos) — bajo por local, escala con el uso.
- **Soporte y garantía** — clave para retención; cubierto por la suscripción.
- **Ventas y marketing** — ver [marketing](../marketing/).
- **Stock/producción** — capital de trabajo para fabricar series.

---

## Estrategia de entrada (go-to-market)

1. **1 gimnasio piloto en Córdoba** (idealmente con relación previa): instalar 1–2 columnas,
   medir uso, juntar testimonio y video real.
2. **Caso de éxito** → usarlo para vender a otros gimnasios de Córdoba (boca a boca + outreach).
3. **Estandarizar** el producto y la instalación para bajar costos y tiempos.
4. **Escalar por segmento**: gimnasios → cadenas de gym → coworkings → clubes → aeropuertos.

---

## Métricas del negocio a seguir

- **CAC** (costo de adquirir un local) vs **LTV** (hardware + suscripción en el tiempo).
- **MRR** (ingreso recurrente mensual) y churn de locales.
- **Margen bruto por columna** real (post-cotizaciones).
- **Uso por puerta/día** (prueba de valor y base para pago por uso).

---

## Riesgos y mitigación

| Riesgo | Mitigación |
|---|---|
| Costo de hardware alto (Argentina/importación) | Compra por volumen, componentes locales, diseño frugal |
| Ciclo de venta lento a locales | Modelo as-a-service / financiación; empezar por conocidos |
| Competencia (lockers electrónicos importados) | Diferenciación: NFC sin app + malla + soporte local + estética |
| Dependencia del WiFi del local | Malla ESP-NOW + modo degradado ([arquitectura](02-arquitectura-tecnica.md#6-modo-degradado-sin-internet)) |
| Soporte técnico a distancia | Panel con diagnóstico remoto; red de instaladores |

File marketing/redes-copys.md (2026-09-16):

# Marketing · Copies de redes + guion de animación

> Contenido listo para publicar. **Vos publicás** desde tus cuentas — yo no tengo acceso a
> tus redes. Usá la voz de [`../brand/identidad.md`](../brand/identidad.md): directa, argentina,
> con carácter.

---

## Bio / presentación

**Instagram bio:**
> 🔐 LockIt — Casilleros inteligentes que se abren con un toque.
> Sin llaves. Sin candados. NFC + panel para tu local. 📍 Córdoba, AR
> 👇 Cómo funciona

**Una línea (elevator):**
> LockIt convierte cualquier casillero en uno inteligente: tus clientes lo abren acercando el
> celu, y vos lo controlás todo desde un panel.

---

## Post de lanzamiento (carrusel)

1. **Portada:** "Tu locker, un toque." (con el 3D del locker)
2. "Sin llaves. Sin candados. Sin fichas."
3. "Acercás el celu al tag NFC → se abre. Sin instalar ninguna app."
4. "¿Libre u ocupado? Se ve de una: puerta transparente o indicador luminoso."
5. "Los lockers se hablan entre sí por WiFi y te muestran todo en un panel."
6. "Dos líneas: Clear (transparente) y Glow (opaca + aro LED de color)."
7. **Cierre/CTA:** "Hecho en Córdoba 🇦🇷. ¿Tenés un gym o local? Escribinos. → @lockit"

**Caption:**
> El casillero no cambió en 50 años. Nosotros lo estamos cambiando. 🔐
> LockIt: acercás el celu, se abre. Cero llaves, cero candados, cero fichas — y vos controlás
> todo desde un panel.
> Estamos arrancando en Córdoba y buscamos gimnasios para el piloto. ¿Se te ocurre uno? 👇
> #Córdoba #Gimnasios #Tecnología #NFC #Emprender #HechoEnCórdoba

---

## Guion de Reel #1 — "El tap mágico" (15–20 s)

| Tiempo | Imagen | Texto en pantalla | Audio |
|---|---|---|---|
| 0–2 s | Persona llega al vestuario con la mochila | "Perdiste la llave otra vez." | música in |
| 2–5 s | Primer plano: acerca el celu al tag NFC | "¿Y si no hubiera llave?" | *tap* |
| 5–8 s | La puerta se abre sola (LED verde → ) | "Un toque. Se abre." | *click* |
| 8–12 s | Guarda las cosas, cierra, LED ámbar | "Se traba solo. Vos, tranqui." | beat |
| 12–16 s | El 3D del locker girando (de la landing) | "LockIt · casilleros inteligentes" | drop |
| 16–20 s | Logo + CTA | "Córdoba 🇦🇷 · Escribinos" | outro |

> **Tip:** el clip del **3D que se arma/desarma** de la landing es oro para el cierre.

---

## Guion de Reel #2 — "Detrás de escena / hecho en Córdoba" (20–30 s)

- Del CAD en pantalla → al corte en el taller → al gabinete armado → al locker funcionando.
- Texto: "De un plano… a un producto. Diseñado y fabricado en Córdoba."
- Cierre: "LockIt. Tu locker, un toque."

---

## Ideas de contenido (calendario simple)

| Semana | Post | Reel |
|---|---|---|
| 1 | Carrusel de lanzamiento | Reel #1 "El tap mágico" |
| 2 | "Clear vs Glow" (comparativa) | Detrás de escena (CAD → taller) |
| 3 | "3 problemas del casillero de siempre" | El 3D girando + specs |
| 4 | Encuesta: "¿Qué locker tenés en tu gym?" | Testimonio / avance del piloto |

---

## Hashtags base

`#LockIt #Córdoba #HechoEnCórdoba #Gimnasios #Fitness #NFC #Tecnología #Emprender #Coworking #Innovación`

---

## Kit de placas (archivos de diseño)

Las placas están diseñadas en [`redes/`](redes/) como un **canvas de Claude Design**
(`kit-redes-lockit.html`) — se abre, se edita a mano y se **exporta cada placa a PNG**.

| Artboard | Uso | Medida |
|---|---|---|
| `Perfil.dc.html` | Foto de perfil | 1080×1080 |
| `Main.dc.html` | Carrusel 1 · Hook "Tu locker, un toque" | 1080×1080 |
| `Problema.dc.html` | Carrusel 2 · El problema | 1080×1080 |
| `ComoFunciona.dc.html` | Carrusel 3 · Acercás, se abre | 1080×1080 |
| `Lineas.dc.html` | Carrusel 4 · Clear vs Glow | 1080×1080 |
| `ParaQuien.dc.html` | Carrusel 5 · Segmentos (gimnasios ancla) | 1080×1080 |
| `CTA.dc.html` | Carrusel 6 · CTA | 1080×1080 |
| `Testimonios.dc.html` | Testimonios (plantilla con placeholders) | 1080×1080 |
| `Precios.dc.html` | Precios (planes, montos placeholder) | 1080×1080 |
| `Panel.dc.html` | Pantallazo del panel del local | 1080×1080 |
| `StoryAnuncio.dc.html` | Story de anuncio | 1080×1920 |
| `reel.html` | Reel animado (grabar en pantalla) | 9:16 |

> Reemplazá `@lockit` por tu handle real cuando lo tengas. El reel se **graba en pantalla**
> (loop de ~12 s) y se sube como reel/short.

### Caption lista para el carrusel de lanzamiento
> El casillero no cambió en 50 años. Nosotros lo estamos cambiando. 🔐
> **LockIt**: acercás el celu y se abre. Cero llaves, cero candados, cero fichas — y el local
> controla todo desde un panel.
> Estamos arrancando en Córdoba y buscamos gimnasios para el piloto. ¿Conocés uno? Etiquetalo 👇
> `#Córdoba #Gimnasios #Fitness #Tecnología #NFC #Emprender #HechoEnCórdoba`

### Caption para el reel
> Sin llaves. Sin candados. Un toque. 🔐 Así de simple va a ser tu locker.
> LockIt · casilleros inteligentes, hechos en Córdoba. ¿Tenés un gym? Escribinos.

### Caption para la placa del panel
> No es solo la puerta: el local ve todo en vivo. 📊 Cuáles están libres, ocupados o
> reservados, cuántos usos hubo hoy — todo desde un panel, sin dar vueltas por el vestuario.
> LockIt · casilleros inteligentes, hechos en Córdoba.
> `#Gimnasios #Gestión #Tecnología #NFC #Córdoba`
> `#LockIt #Córdoba #Gimnasios #NFC #Innovación`

---

## Nota importante

Yo (Claude) **no publico** en tus redes ni administro tus cuentas — no tengo acceso y no
sería seguro. Te dejo todo el contenido listo para que lo subas vos. Si querés, puedo:
- Adaptar los copies a un tono más formal (LinkedIn) o más informal (TikTok).
- Escribir más variantes de captions.
- Preparar los textos exactos para cada slide del carrusel.

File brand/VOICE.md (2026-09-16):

# VOICE.md · LockIt — cómo escribir (sin "tells" de IA)

> Guía para TODO el texto de LockIt (web, redes, mails, panel, decks). Destila
> **Humanizer** (blader/humanizer) y **Stop-Slop** (hardikpandya/stop-slop) al español rioplatense.
> Regla base: **no inventar**. Si falta un dato (precio, fecha, nombre), va como `[placeholder]`,
> no se fabrica.

## Tono LockIt
Directo, argentino, seguro. Técnico cuando toca, humano cuando vende. Frases cortas. Voz activa.
Nada de vender humo. Ejemplo: *"Acercás el celu y se abre."* — no *"Revolucioná la experiencia
de tus casilleros."*

## Prohibido (banned)
**Palabras/arranques:** "En el mundo de hoy", "En la era de", "revolucioná", "elevá tu",
"potenciá", "seamless", "impecable/de otro nivel" como muletilla, "no es solo X, es Y",
"imaginá un…", "¿y si te dijera que…?", "en esencia / al final del día".
**Muletillas de IA:** "delve/profundicemos", "testament/prueba de ello", "landscape/panorama"
de relleno, "showcasing/destacando", adverbios de relleno ("simplemente", "realmente",
"literalmente").
**Cierres dramáticos:** fragmentos de una línea después de cada sección ("Así de simple." usado
en todo). Un cierre está bien; de a diez, no.
**Puntuación:** nada de guiones largos (—) por todos lados; usar punto, coma, dos puntos o
paréntesis. Comillas rectas, no curvas. Sentence case en títulos, sin emojis decorativos.

## Estructura (clichés a evitar)
- Contrastes binarios ("no X, sino Y") → afirmá directo.
- Listas por negación ("no llaves, no candados, no fichas") → OK una vez como gancho, no de patrón.
- Triadas forzadas → usá la cantidad de ítems que el sentido pide, no siempre 3.
- Preguntas retóricas de relleno y "objeciones" que nadie hizo.
- Voz de narrador distante → hablá de vos a vos (segunda persona).
- Voz pasiva → nombrá quién hace la acción.

## Reglas de oración
- Voz activa siempre. Verbos directos (es/tiene/abre), no "funciona como" / "sirve para".
- No arrancar oraciones con "Lo que…", "Cómo…", "Por qué…" de relleno.
- Sin fragmentos staccato como efecto. Sin extremos vagos ("todo el mundo", "nunca más").
- Cortá calificadores apilados ("muy", "realmente", "increíblemente").

## Chequeo rápido (Stop-Slop scoring)
Puntuá 1–10 cada eje; abajo de 35/50 = reescribir:
**Directness** · **Rhythm** (variar largo de oración) · **Trust** (fuentes/datos reales, no
autoridad prestada) · **Authenticity** (suena a persona) · **Density** (cero relleno).

## Antes / después (ejemplos LockIt)
- ❌ "Revolucioná la seguridad de tus casilleros con tecnología de última generación."
  ✅ "Sacá las llaves del vestuario. Se abre con el celu."
- ❌ "No es solo un locker, es una experiencia." → ✅ "Un locker que se abre con un toque."
- ❌ "En el mundo del fitness actual, la comodidad es clave —y nosotros la entendemos."
  ✅ "En el gym nadie quiere cargar una llave. Por eso LockIt se abre con el celu."

> Herramientas vivas: se pueden instalar como skills — Humanizer (blader/humanizer) y
> Stop-Slop (hardikpandya/stop-slop) reescriben/puntúan texto dentro de Claude.

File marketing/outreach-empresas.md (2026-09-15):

# Marketing · Outreach a empresas (borradores)

> Plantillas para contactar gimnasios y locales de Córdoba. **IMPORTANTE:** estos son
> **borradores para que los revises y envíes vos**. No envío mails en frío a empresas reales
> por vos: es una acción externa e irreversible, necesita tu lista y tu OK, y el mailing masivo
> mal hecho quema tu dominio y tu marca. Abajo, un checklist para hacerlo bien.

---

## Checklist para no spamear (leé antes de enviar)

- [ ] **Segmentá:** empezá por gimnasios con los que tengas alguna relación o cercanía.
- [ ] **Personalizá:** nombre del gym, algo específico de ellos. Nada de "Estimado señor/a".
- [ ] **Poco volumen, mucha calidad:** 10–20 mensajes bien hechos > 500 genéricos.
- [ ] **Canal correcto:** en gimnasios, **WhatsApp/Instagram DM** suele funcionar mejor que el mail.
- [ ] **Valor primero:** ofrecé una demo/piloto, no "comprá ya".
- [ ] **Seguimiento respetuoso:** 1 recordatorio como mucho. Si no responden, listo.
- [ ] **Cumplí la ley:** identificate, ofrecé no volver a escribir, respetá si dicen que no.

---

## Plantilla A — Mail a gimnasio (frío-templado)

```
Asunto: Sacá las llaves de los lockers de [Gimnasio]

Hola [nombre], ¿cómo va?

Soy [tu nombre], de LockIt (somos de Córdoba). Estamos lanzando un sistema de casilleros
inteligentes que se abren acercando el celular — sin llaves, sin candados y sin fichas — y
que te deja ver y controlar la ocupación desde un panel.

Lo pensamos justo para gimnasios: menos quejas por llaves perdidas, mejor imagen y una
experiencia más moderna para tus socios.

Estamos armando un piloto en Córdoba y me encantaría mostrarte cómo funciona (te paso un
link con el producto en 3D y, si te copa, coordinamos una demo).

¿Te sirve que te cuente más por acá o por WhatsApp?

Un saludo,
[tu nombre] — LockIt
[teléfono] · [link a la landing]
```

---

## Plantilla B — WhatsApp / DM (corto)

```
Hola [nombre]! Somos LockIt, de Córdoba 🔐. Hacemos casilleros que se abren con el celu
(sin llaves ni candados) y con panel de control para el local. Estamos buscando 1–2
gimnasios para un piloto. ¿Te muestro cómo funciona? Te paso el 3D 👇 [link]
```

---

## Plantilla C — Seguimiento (si no respondieron, 1 sola vez)

```
Hola [nombre], te reescribo por las dudas se haya perdido el mensaje 🙂
Si te interesa modernizar los lockers de [Gimnasio] con apertura por celular, en 5 minutos te
muestro cómo funciona y qué implicaría un piloto. Si no es el momento, ningún problema —
¡gracias igual!
[tu nombre] — LockIt
```

---

## Plantilla D — LinkedIn (coworkings / oficinas, más formal)

```
Hola [nombre], vi que en [empresa] manejan [coworking/oficinas] y quería mostrarte LockIt:
casilleros inteligentes con apertura por NFC (sin app) y panel de gestión, diseñados y
fabricados en Córdoba. Ideal para asignar lockers a miembros/empleados con control y buena
estética. ¿Te comparto una demo?
```

---

## Cómo armar tu lista (vos)

- Gimnasios y cadenas de Córdoba que conozcas o te queden cerca.
- Coworkings, clubes, escuelas de danza/música, natatorios.
- Contactos propios que tengan un local con vestuario/casilleros.

> Cuando tengas la lista, puedo ayudarte a **personalizar cada mensaje** (uno por uno) y a
> ordenar el seguimiento. Pero el envío lo hacés vos, desde tus cuentas.

---

## Qué puedo hacer yo (Claude) y qué no

**Sí:**
- Escribir y personalizar los mensajes.
- Adaptar tono por canal (mail / WhatsApp / LinkedIn).
- Armar un guion de demo y una mini-presentación.

**No (sin tu autorización explícita y tu lista):**
- Enviar mails o mensajes a empresas reales por vos.
- Publicar en tus redes o administrar tus cuentas.

> Si querés que prepare los mensajes para una lista concreta, pasámela y los dejo listos para
> que los mandes.

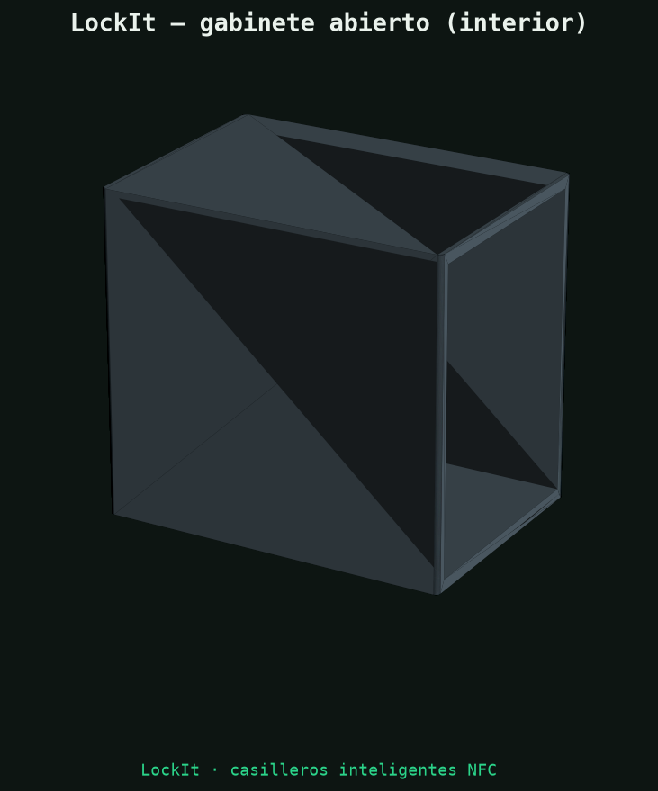
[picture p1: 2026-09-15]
cad/exports/renders/lockit_render_04.png

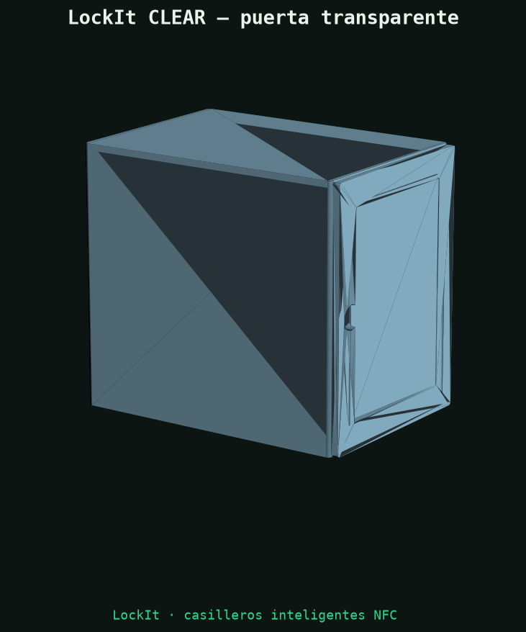
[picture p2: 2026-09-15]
cad/exports/renders/lockit_render_01.png

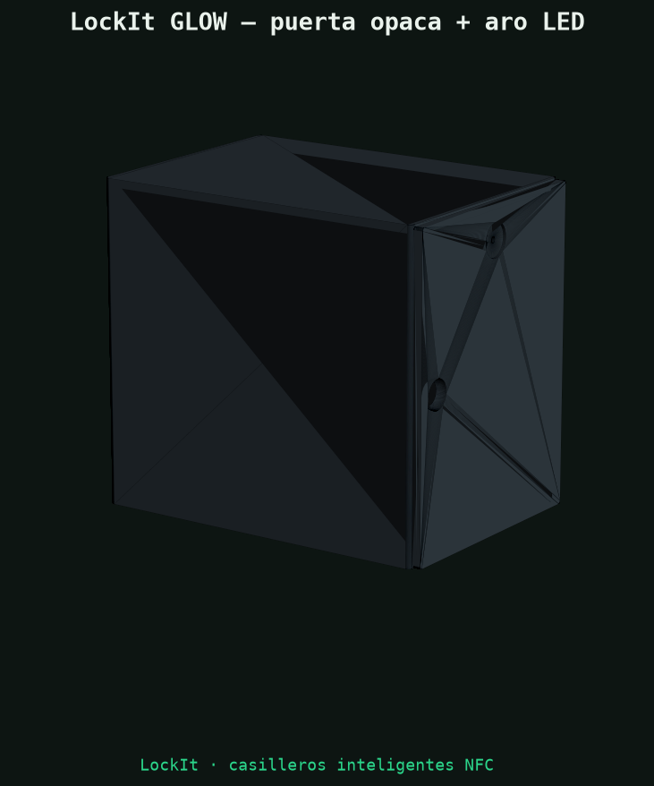
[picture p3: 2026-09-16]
cad/exports/renders/lockit_render_03.png

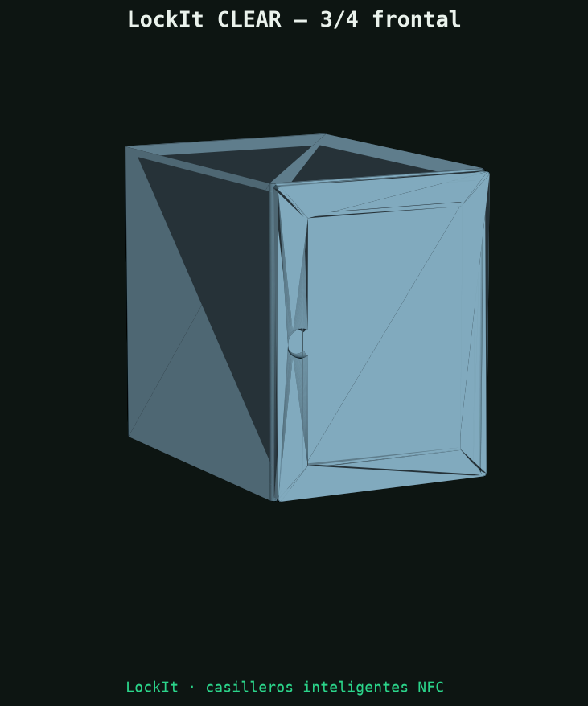
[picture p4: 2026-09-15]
cad/exports/renders/lockit_render_02.png

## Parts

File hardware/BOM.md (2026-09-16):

# Hardware · Bill of Materials (BOM)

> Lista de materiales de **un nodo (una puerta)** y del **gateway**. Precios **estimados** a
> septiembre 2025, en USD (referencia internacional) y ARS (a validar en Córdoba/MercadoLibre).
> Tomar como orden de magnitud para cotizar, no como precio cerrado. TC de referencia usado:
> **~1 USD = 1.400 ARS** (ajustar al cambio del día).

## Nodo por puerta — variante base (tag NFC pasivo)

| # | Componente | Detalle | Cant. | USD c/u | USD total |
|---|---|---|---|---|---|
| 1 | **ESP32** | WROOM-32 devkit (o C3 más barato) | 1 | 4.5 | 4.5 |
| 2 | **Cerradura eléctrica 12 V** | Solenoide tipo "cabinet lock" (consume solo al abrir) | 1 | 5.0 | 5.0 |
| 3 | **MOSFET driver** | IRLZ44N + resistencias + diodo flyback | 1 | 0.8 | 0.8 |
| 4 | **Sensor Hall + imán** | A3144 (o reed switch ~0.3) + imán de neodimio | 1 | 0.6 | 0.6 |
| 5 | **Tag NFC pasivo** | NTAG213/215 sticker (grabado con URL NDEF) | 1 | 0.3 | 0.3 |
| 6 | **Aro LED de estado** | Anillo WS2812 direccionable (12–16 px), Clear y Glow | 1 | 1.5 – 3.0 | 1.5 – 3.0 |
| 7 | **Buck converter** | 12 V → 3.3/5 V (MP1584 o similar) | 1 | 0.7 | 0.7 |
| 8 | **PCB / protoboard + conectores** | placa del nodo, borneras, cableado | 1 | 2.0 | 2.0 |
| 9 | **Gabinete electrónico** | caja plástica del nodo (o impreso 3D) | 1 | 1.0 | 1.0 |
| | | | | **Subtotal nodo** | **≈ USD 16.4 – 18.9** |

- **Variante Clear:** mismo aro LED sobre puerta transparente (~USD 16.4 / **≈ ARS 23.000**).
- **Variante Glow:** mismo aro LED sobre puerta opaca; el costo extra está en la puerta, no en el indicador.
- **Nodo "Pro" (con lector NFC PN532):** +USD 4–8 → apertura offline y credencial física.

> ⚠️ La **cerradura** y la **puerta** son los ítems que más mueven el costo. Comprar por
> volumen (50–100 u.) baja el nodo a **~USD 11–13** por puerta.

## Gateway (uno por local / por zona)

| # | Componente | Detalle | Cant. | USD |
|---|---|---|---|---|
| 1 | ESP32 | Igual que nodo, con WiFi al router del local | 1 | 4.5 |
| 2 | Fuente 12 V | Alimenta la columna de cerraduras (ej. 12 V 5 A) | 1 | 8.0 |
| 3 | Caja + antena | Gabinete con mejor antena WiFi | 1 | 5.0 |
| | | | **Total gateway** | **≈ USD 17.5** |

> El gateway puede ser **uno de los nodos** con el firmware en rol gateway (ahorra hardware),
> o un dispositivo dedicado si el local es grande.

## Costeo de una columna de 4 puertas (variante Clear)

| Concepto | USD | ARS aprox. |
|---|---|---|
| 4 nodos Clear × ~16.4 | 65.6 | 92.000 |
| Prorrateo gateway (1 cada ~8 puertas) | 8.8 | 12.300 |
| Fuente 12 V compartida | (incluida en gateway) | — |
| **Electrónica por columna de 4** | **≈ 74** | **≈ 104.000** |

> A esto se le suma la **estructura física** (melamina/chapa, herrajes, puertas, corte y
> armado) que cotiza el taller — ver
> [`../docs/04-fabricacion-cordoba.md`](../docs/04-fabricacion-cordoba.md).

## Dónde comprar (Argentina / Córdoba)

- **ESP32, sensores, MOSFET, buck, aro LED WS2812:** MercadoLibre, Nubbeo, Vistronica, Electrocomponentes.
- **Cerraduras solenoide 12 V "cabinet lock":** MercadoLibre / AliExpress (importar por volumen).
- **Tags NFC NTAG213:** MercadoLibre / importación (baratísimos por cantidad).
- **Fuentes 12 V:** proveedores de electrónica locales de Córdoba.

## Notas de ingeniería

- **Diodo flyback obligatorio** en paralelo a la cerradura (protege el MOSFET del pico inductivo).
- Cerradura **activada por pulso corto** (150–250 ms), nunca energizada de forma continua
  (calienta y consume).
- Un imán de neodimio chico en la puerta + Hall en el marco da lectura confiable de cierre.
- Todo el detalle de conexiones en [`esquematico.md`](esquematico.md).

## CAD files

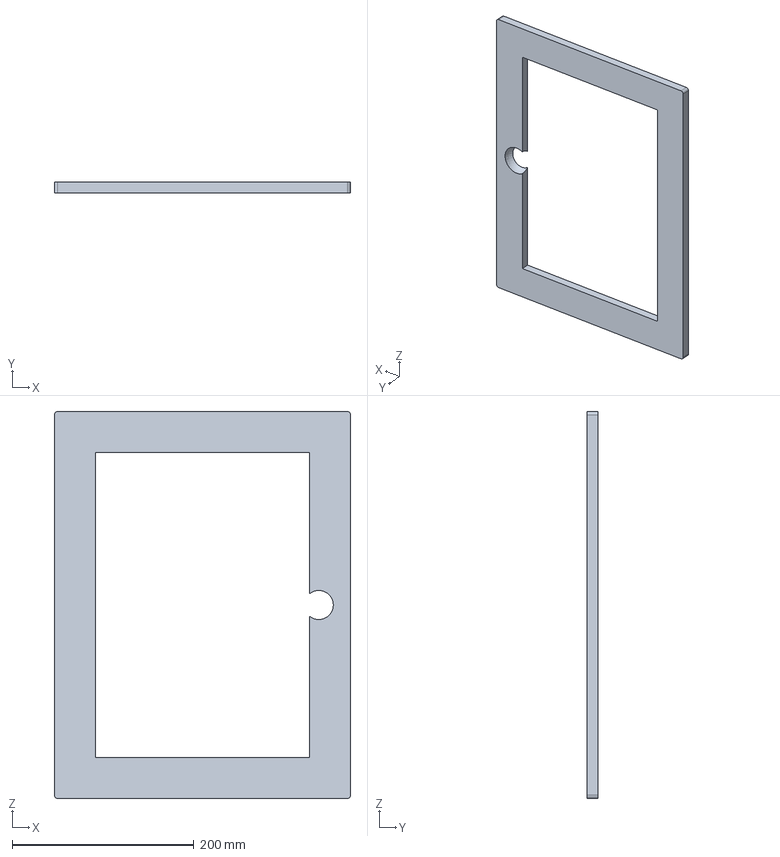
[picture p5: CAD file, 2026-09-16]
cad/exports/lockit_clear_puerta.step
326.0 x 12.0 x 426.0 mm

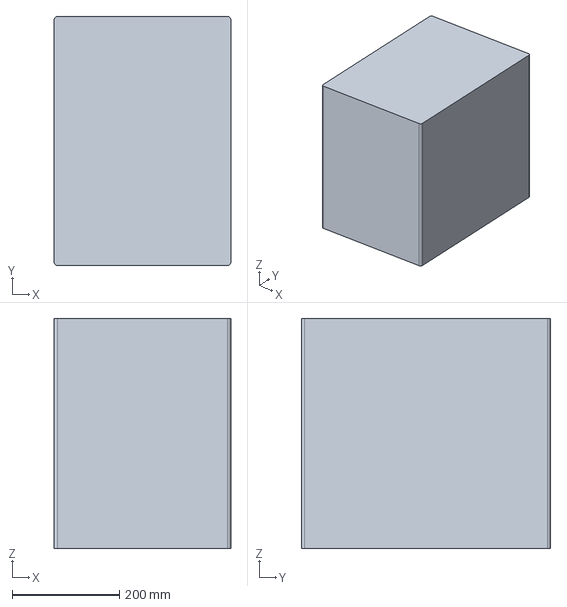
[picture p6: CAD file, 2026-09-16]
cad/exports/lockit_clear_gabinete.step
330.0 x 465.0 x 430.0 mm

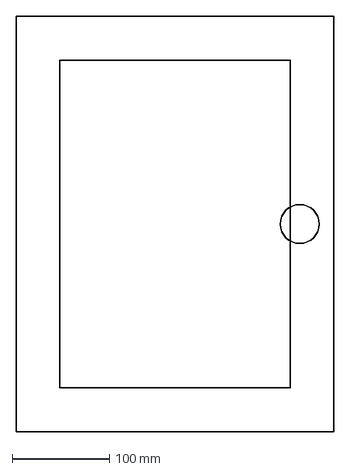
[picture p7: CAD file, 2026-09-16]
cad/exports/lockit_clear_puerta_corte2d.dxf
326.0 x 426.0 mm

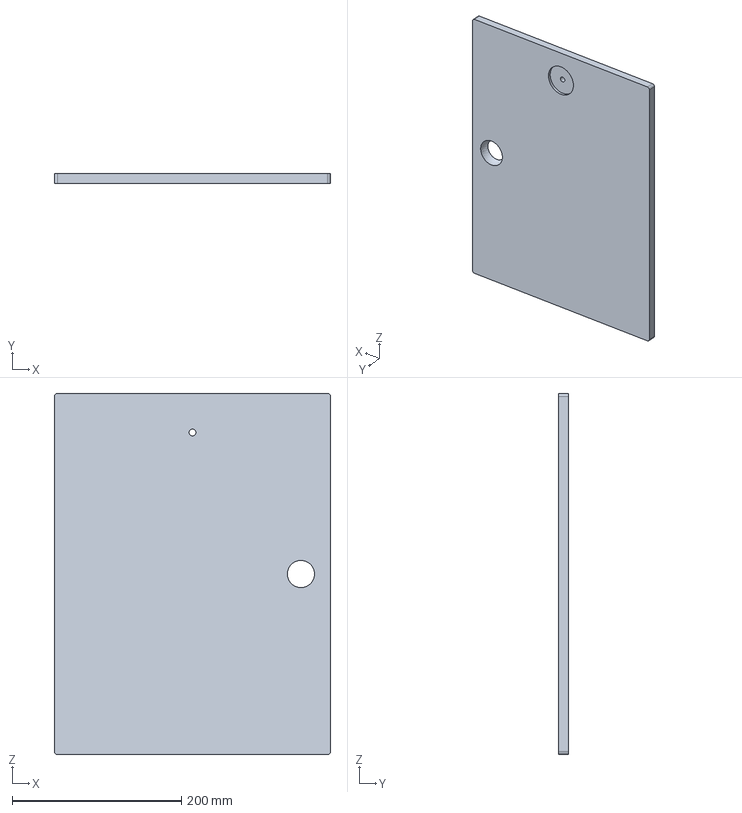
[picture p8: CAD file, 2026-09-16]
cad/exports/lockit_glow_puerta.step
326.0 x 12.0 x 426.0 mm

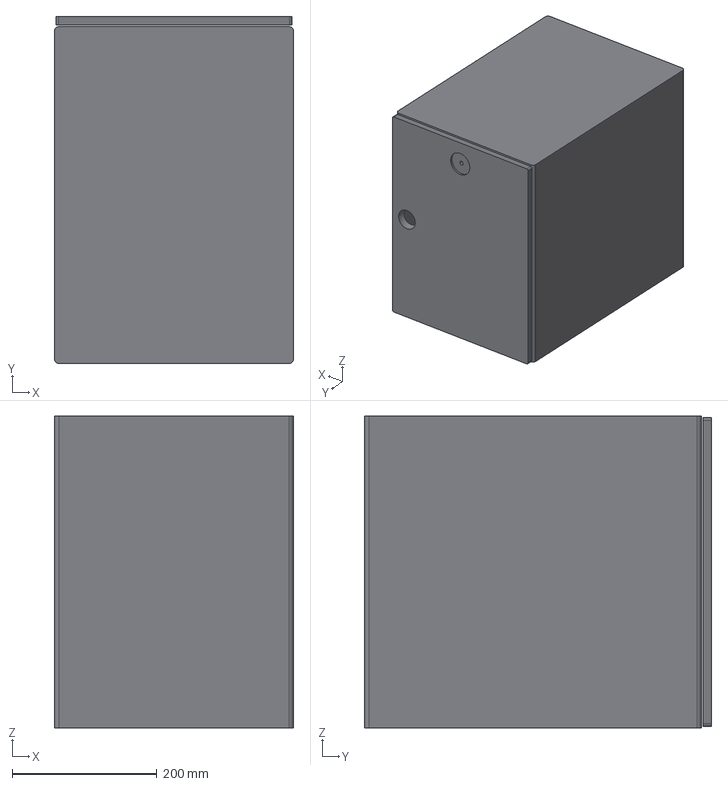
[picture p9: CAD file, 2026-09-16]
cad/exports/lockit_glow_modulo.step
330.0 x 479.0 x 430.0 mm
gabinete
puerta

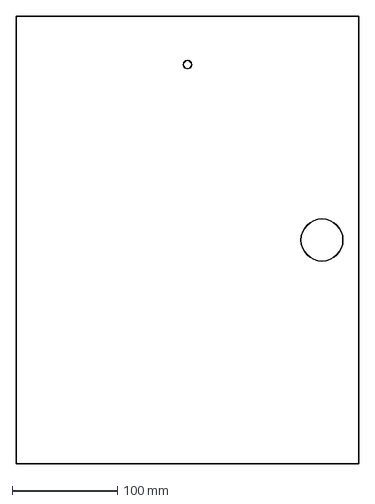
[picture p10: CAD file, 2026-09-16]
cad/exports/lockit_glow_puerta_corte2d.dxf
326.0 x 426.0 mm

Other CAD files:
cad/exports/lockit_glow_gabinete.step
cad/exports/lockit_clear_modulo.step
cad/exports/lockit_clear_gabinete.stl
cad/exports/lockit_clear_modulo.stl
cad/exports/lockit_clear_puerta.stl
cad/exports/lockit_glow_gabinete.stl
cad/exports/lockit_glow_modulo.stl
cad/exports/lockit_glow_puerta.stl

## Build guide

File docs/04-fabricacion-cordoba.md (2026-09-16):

# 04 · Fabricación en Córdoba

> Cómo pasar del CAD ([`../cad/`](../cad/)) a un locker físico, con proveedores y procesos
> reales de Córdoba, Argentina. Incluye una **plantilla de cotización** lista para mandar a
> talleres.

---

## Qué se manda a fabricar

Un módulo LockIt tiene tres "paquetes" de fabricación:

| Paquete | Piezas | Proceso | Archivo que se manda |
|---|---|---|---|
| **A. Estructura** | Gabinete (5 paneles), puerta, dividers, base | Corte CNC/láser + plegado o armado | `*.dxf` de corte + `*.step` de referencia |
| **B. Electrónica** | Nodo ESP32, cerradura, sensor, indicador | Compra + ensamble en placa | [`../hardware/BOM.md`](../hardware/BOM.md) |
| **C. Terminación** | Pintura/laminado, herrajes, numeración, aro LED | Pintura + montaje | Especificación de color y acabado |

---

## Procesos según material

### Opción melamina (recomendada para prototipo y piloto)
- **Corte:** router CNC sobre placa de melamina hidrófuga 15 mm.
- **Armado:** tornillería + tarugos / minifix; cantos con ABS.
- **Puerta Clear:** marco de melamina + **policarbonato** cortado a medida (láser o sierra).
- **Ventaja:** rápido, barato, muchos talleres en Córdoba lo hacen (mueblerías/carpinterías CNC).

### Opción chapa plegada (para versión robusta/premium)
- **Corte:** láser sobre chapa (acero 0.9–1.2 mm).
- **Plegado:** plegadora CNC.
- **Terminación:** pintura en polvo (termolacado) — muy resistente en vestuarios.
- **Ventaja:** antivandálico, durabilidad; **Contra:** más caro, menos talleres.

---

## Dónde cotizar en Córdoba (tipos de proveedor)

| Necesidad | Tipo de proveedor | Cómo buscar |
|---|---|---|
| Corte CNC melamina | Carpintería CNC / mueblería a medida | "corte CNC melamina Córdoba", parques industriales |
| Corte láser chapa + plegado | Taller metalúrgico / corte láser | "corte láser chapa Córdoba", polo metalúrgico |
| Policarbonato/acrílico a medida | Corte láser acrílico / cartelería | "corte acrílico Córdoba", "policarbonato Córdoba" |
| Pintura en polvo | Termolacado / pintura industrial | "termolacado Córdoba" |
| Electrónica y ensamble | Casas de electrónica + freelance | MercadoLibre + electrónicos locales |
| Impresión 3D (prototipo de piezas) | Servicios de impresión 3D FDM/resina | "impresión 3D Córdoba" |

> Estrategia recomendada: **melamina para el prototipo** (rápido y barato para validar), y
> cotizar **chapa en paralelo** para tener la versión "producto final" lista cuando escale.

---

## Plantilla de cotización (copiar y enviar)

> Copiá este texto, adjuntá los archivos `cad/exports/*.dxf` y `*.step` y las medidas.
> Reemplazá lo que está entre corchetes.

```
Asunto: Cotización — prototipo de casillero (mueble/metal) con corte CNC

Hola [nombre del taller], ¿cómo estás?

Estoy desarrollando un producto de casilleros inteligentes (marca LockIt, Córdoba) y
necesito cotizar la fabricación de un PROTOTIPO de 1 columna de 4 puertas.

DETALLE:
- Material: [melamina hidrófuga 15 mm / chapa 1 mm plegada] color [grafito/blanco].
- Módulo (x4 apilados): interior 300 x 400 x 450 mm; exterior aprox. 330 x 430 x 465 mm.
- Puerta por módulo: [policarbonato con marco (línea Clear) / opaca con ventana (línea Glow)].
- Incluye: paneles laterales, fondo con ranuras de ventilación, 3 divisiones horizontales,
  base/zócalo y tapa. Alojamiento interno para caja de electrónica (60 x 80 x 40 mm) por puerta.
- Herrajes: bisagras [ocultas/piano] y previsión de cerradura eléctrica embutida (la
  electrónica la proveo yo).

ADJUNTO:
- Planos de corte 2D (DXF) de la puerta y referencia 3D (STEP).
- (Puedo pasar el resto de los planos de corte al confirmar el material.)

NECESITO:
1) Precio del PROTOTIPO (1 columna de 4 puertas), armado.
2) Precio estimado por unidad para una PRIMERA SERIE de [10 / 25 / 50] columnas.
3) Plazo de entrega del prototipo.
4) Qué necesitás de mi lado para arrancar.

¡Gracias! Quedo atento.
[Tu nombre] — LockIt — [tu teléfono/mail]
```

---

## Costeo objetivo (orden de magnitud)

> A **validar** con las cotizaciones reales. Sirve para saber si el negocio cierra.

| Concepto (por columna de 4 puertas) | Estimado ARS | Nota |
|---|---|---|
| Estructura melamina (corte + armado) | 180.000 – 320.000 | Muy variable por taller |
| Puertas (policarbonato x4 con marco) | 90.000 – 160.000 | Clear; Glow: melamina + rebaje para aro LED |
| Herrajes + tornillería | 30.000 – 60.000 | |
| Electrónica (4 nodos + prorrateo gateway) | ≈ 104.000 | Ver [BOM](../hardware/BOM.md) |
| Ensamble + pruebas | 60.000 – 120.000 | Mano de obra |
| **Total prototipo por columna** | **≈ 460.000 – 760.000 ARS** | ≈ USD 330 – 540 |

> Al escalar (series de 25–50), la estructura y la electrónica bajan fuerte por volumen.
> El objetivo es un **costo por puerta** que deje margen sano según el
> [modelo de negocio](05-modelo-negocio.md).

---

## Normativa y seguridad (a tener en cuenta)

- **Eléctrica:** instalación de 12 V con fuente certificada, fusibles, cableado en canaleta.
  Para venta comercial, revisar requisitos de seguridad eléctrica y garantía.
- **Materiales:** en vestuarios húmedos, priorizar materiales que no se hinchen (hidrófugo/HPL).
- **Accesibilidad:** prever al menos una fila a altura accesible por instalación.
- **Facturación/IVA:** definir con contador la estructura para vender a empresas.

---

## Siguiente paso concreto

1. Elegir material del prototipo (recomendado: **melamina**).
2. Generar los DXF definitivos (`python cad/build.py`) y mandar la **plantilla de cotización**
   a 3–5 talleres.
3. Comprar la electrónica del [BOM](../hardware/BOM.md) para 1 columna.
4. Armar y probar el primer nodo (ver [roadmap](06-roadmap.md)).

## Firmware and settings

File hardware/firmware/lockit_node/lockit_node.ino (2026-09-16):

// =============================================================================
// LockIt · lockit_node.ino — Firmware del nodo (ESP32)
// Esqueleto funcional: máquina de estados + control de cerradura + sensor de
// puerta + stubs de red (ESP-NOW / MQTT). / Functional skeleton.
//
// NOTA: la capa de red real (peers ESP-NOW, protocolo de mensajes, MQTT) se
// completa en la Etapa 2 al armar el primer nodo físico. Los TODO marcan dónde.
// =============================================================================
#include <Arduino.h>
#include "config.h"

// ---- Estados del locker / Locker states ------------------------------------
enum LockerState { LIBRE, RESERVADO, ABRIENDO, ABIERTO, OCUPADO };
LockerState state = LIBRE;
unsigned long sessionStart = 0;

// ---------------------------------------------------------------------------
// Helpers de hardware / Hardware helpers
// ---------------------------------------------------------------------------
bool doorIsClosed() {
  int v = digitalRead(PIN_DOOR);
  bool closed = DOOR_CLOSED_IS_LOW ? (v == LOW) : (v == HIGH);
  return closed;
}

void pulseLock() {
  // Pulso corto para liberar la cerradura. NUNCA energizar de forma continua.
  digitalWrite(PIN_LOCK, HIGH);
  delay(LOCK_PULSE_MS);
  digitalWrite(PIN_LOCK, LOW);
}

void showState(LockerState s) {
  // Aro LED WS2812 en ambas variantes (Clear y Glow): color por estado.
  // TODO: implementar con FastLED/Adafruit_NeoPixel sobre PIN_LEDRING (LEDRING_COUNT).
  switch (s) {
    case LIBRE:      /* verde  */ break;
    case RESERVADO:  /* ámbar  */ break;
    case ABRIENDO:   /* animación suave */ break;
    case ABIERTO:    /* azul   */ break;
    case OCUPADO:    /* azul fijo */ break;
  }
}

void setState(LockerState s) {
  state = s;
  showState(s);
  reportState();   // avisar al gateway/nube
}

// ---------------------------------------------------------------------------
// Red / Network (stubs)
// ---------------------------------------------------------------------------
void netSetup() {
#if DEVICE_ROLE == ROLE_GATEWAY
  // TODO: WiFi.begin(WIFI_SSID, WIFI_PASS); conectar MQTT (PubSubClient/TLS).
#endif
  // TODO: esp_now_init(); registrar PMK/LMK; agregar peers de la malla.
}

void reportState() {
  // TODO: enviar STATE por ESP-NOW al gateway (id, estado, puerta, rssi).
  //       El gateway lo publica por MQTT a la nube.
}

// Se llama cuando llega un comando OPEN (por ESP-NOW / MQTT). / On OPEN command.
void onOpenCommand() {
  if (state == RESERVADO || state == OCUPADO) {
    setState(ABRIENDO);
    pulseLock();
    setState(ABIERTO);
    sessionStart = millis();
  }
}

// Se llama cuando la app reserva este locker. / On reservation.
void onReserve() {
  if (state == LIBRE) {
    setState(RESERVADO);
    sessionStart = millis();
  }
}

// ---------------------------------------------------------------------------
// setup / loop
// ---------------------------------------------------------------------------
void setup() {
  Serial.begin(115200);
  pinMode(PIN_LOCK, OUTPUT);
  digitalWrite(PIN_LOCK, LOW);
  pinMode(PIN_DOOR, INPUT);
  pinMode(PIN_LEDRING, OUTPUT);   // aro WS2812 (la lib toma este pin de data)

  netSetup();
  setState(LIBRE);
  Serial.printf("LockIt nodo %s-%s listo. Rol=%d Variante=%d\n",
                LOCKER_SITE, LOCKER_ID, DEVICE_ROLE, VARIANT);
}

void loop() {
  // 1) Transiciones por sensor de puerta / door sensor transitions
  static bool lastClosed = true;
  bool closed = doorIsClosed();
  if (closed != lastClosed) {
    delay(DOOR_DEBOUNCE_MS);
    closed = doorIsClosed();
    if (closed != lastClosed) {
      lastClosed = closed;
      if (state == ABIERTO && closed) setState(OCUPADO);   // cerró con cosas
      // (si estaba OCUPADO y abre, el comando OPEN maneja la transición)
    }
  }

  // 2) Timeout de sesión / session timeout -> volver a LIBRE si nunca se usó
  if (state == RESERVADO && millis() - sessionStart > SESSION_TIMEOUT_MS) {
    setState(LIBRE);
  }

  // 3) TODO: procesar mensajes de red entrantes (OPEN/ASSIGN/PING).
  delay(10);
}

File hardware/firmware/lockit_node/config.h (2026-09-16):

// =============================================================================
// LockIt · config.h  — Configuración del nodo (pines, rol, red, tiempos)
// Toda la configuración editable del firmware vive acá. / All tunables live here.
// =============================================================================
#pragma once

// ---- Rol del dispositivo / Device role -------------------------------------
#define ROLE_NODE     0
#define ROLE_GATEWAY  1
#define DEVICE_ROLE   ROLE_NODE      // cambiar a ROLE_GATEWAY en el nodo puente

// ---- Identidad del locker / Locker identity --------------------------------
#define LOCKER_SITE   "GYM01"        // id del local / site id
#define LOCKER_ID     "014"          // id de esta puerta / this door id

// ---- Variante / Variant ----------------------------------------------------
// Ambas usan el mismo aro LED direccionable (WS2812); cambia solo la puerta.
#define VARIANT_CLEAR 0              // puerta transparente + aro LED
#define VARIANT_GLOW  1              // puerta opaca + aro LED
#define VARIANT       VARIANT_CLEAR

// ---- Pines / Pins (ESP32 WROOM-32) -----------------------------------------
#define PIN_LOCK      25             // gate del MOSFET -> cerradura / lock MOSFET gate
#define PIN_DOOR      34             // sensor Hall (input only) / door sensor
#define PIN_LEDRING   26             // data del aro LED WS2812 (Clear y Glow)
#define LEDRING_COUNT 16             // nº de LEDs del aro / ring pixel count

// ---- Tiempos / Timings -----------------------------------------------------
#define LOCK_PULSE_MS       200      // pulso para abrir la cerradura / open pulse
#define DOOR_DEBOUNCE_MS    50       // antirrebote del sensor / sensor debounce
#define SESSION_TIMEOUT_MS  90000    // ventana de sesión (90 s) / session window

// ---- Sensor de puerta / Door sensor logic ----------------------------------
// true = el sensor lee LOW cuando la puerta está CERRADA (imán presente)
#define DOOR_CLOSED_IS_LOW  true

// ---- Red del local (solo GATEWAY) / Site WiFi (gateway only) ---------------
#define WIFI_SSID     "WIFI_DEL_GYM"     // completar en instalación
#define WIFI_PASS     "********"
#define MQTT_HOST     "mqtt.lockit.ar"   // broker de la nube / cloud broker
#define MQTT_PORT     8883               // TLS

// ---- ESP-NOW ----------------------------------------------------------------
// Clave pre-compartida de la malla (16 bytes). Cambiar por local en producción.
#define ESPNOW_PMK    "LockIt_PMK_16by"

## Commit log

2026-09-15 LockIt: fundación del proyecto — arquitectura, CAD 3D, marca y landing con Three.js
    - Estructura del monorepo (docs, hardware, cad, webapp, landing, marketing, brand)
    - Arquitectura técnica completa (ESP32 en malla ESP-NOW, NFC, sensor Hall, seguridad)
    - CAD paramétrico con CadQuery: módulo de gimnasio en 2 variantes (Clear/Glow),
    exporta STEP/STL/DXF de corte + renders
    - Hardware: BOM con costos, esquemático y esqueleto de firmware ESP32
    - Identidad de marca propia (paleta, logo/isotipo SVG, tipografía, motion)
    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
    [lockit_clear_gabinete.step, lockit_clear_gabinete.stl, lockit_clear_modulo.step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]
2026-09-15 docs: fabricación en Córdoba, modelo de negocio, roadmap y marketing
    - 04-fabricacion-cordoba: procesos, proveedores y plantilla de cotización
    - 05-modelo-negocio: modelos de ingreso, pricing y unit economics
    - 06-roadmap: etapas prototipo → piloto → producción
    - marketing: estrategia, copies de redes con guion de animación,
    y borradores de outreach (con checklist anti-spam)
    Claude-Session: https://claude.ai/code/session_01AdUkgiVesmY5kdjwGsyDVG
2026-09-15 rebrand: paleta carbón + oro/ámbar (premium tech, luz cálida)
    - Nueva identidad inspirada en smart gyms de Córdoba (negro+oro, Qivox):
    base carbón cálido + oro como color de marca + coral amigable
    - Landing: rediseño anti-"AI look" (botones, sin rail lateral, redondeos
    y sombras más finos), luz cálida en el 3D, giro 360° completo para ver
    la variante Glow, y menos zoom
    - Logo/isotipo SVG y webapp NFC actualizados a la paleta nueva
    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
2026-09-15 logo candado + rediseño "instrumento técnico" (menos AI-tells, más chiches)
    - Nuevo logo: candado premium en oro con marco interior grabado (evoca la
    puertita del locker) + wordmark; SVGs isotipo/logo y marca inline actualizados
    - Landing rediseñada con lenguaje técnico/blueprint: se sacaron los puntos glow
    (halos), se sumaron marcas de registro en esquinas, anotaciones monospace con
    medidas, nodos/hairlines en el proceso, íconos dibujados (no emojis), ticker,
    numeración de secciones §01–§05 y grilla sutil
    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
2026-09-15 UX fixes + diagrama de uso + 3D realista
    - Legibilidad del hero (velo + text-shadow), eyebrow acortado, variant-chip
    reubicado en mobile, fix del bloque de estado (texto pegado)
    - Copy más limpio y confiado (sin aclaraciones tipo instrucción); ficha técnica
    con lenguaje elevado (cerradura electrónica con tag NFC, sin jerga)
    - Nuevo diagrama de uso: 4 escenas SVG (acercar → abrir → guardar → trabar)
    - 3D mucho más realista: texturas procedurales (rugosidad/cepillado/AO),
    entorno de reflejos tipo estudio, herrajes reales (patas, bisagras, tirador,
    tornillos), sombras 2K + sombra de contacto, luz cálida
    Claude-Session: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
2026-09-15 marketing: kit de redes (canvas de placas) + reel animado
    - marketing/redes/: carrusel de lanzamiento (6 placas 1:1), foto de perfil y
    story, como canvas editable con export PNG; + reel.html animado 9:16 para
    grabar en pantalla. Todo con la marca (carbón+oro, candado, estilo técnico)
    - redes-copys.md: guía del kit + captions listas para postear
    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
2026-09-15 marketing: +placas de testimonios y precios en el kit de redes
    - Testimonios.dc.html (plantilla con placeholders, sin datos falsos)
    - Precios.dc.html (estructura equipo + servicio, montos placeholder)
    - canvas.json: carrusel reordenado a 8 placas; kit republicado
    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
2026-09-16 panel: dashboard del local (demo) — ocupación en vivo y gestión
    - panel/index.html: KPIs, grilla de lockers por columna (libre/ocupada/
    reservada/abierta), detalle con acciones asignar/liberar/abrir (mock JS,
    sin backend), actividad reciente, búsqueda y filtros. Marca carbón+oro.
    - README: índice actualizado con panel/
    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
2026-09-16 diseño: guardrails anti AI-tell (brand/DESIGN.md + CLAUDE.md)
    - brand/DESIGN.md: tokens, lista negra de AI-tells, reglas de ejecución
    ("un gesto distintivo por pieza", referencia-first), sección de referencias
    a completar y checklist pre-publicación
    - CLAUDE.md: memoria del proyecto que hace que toda sesión herede las reglas
    de diseño, convenciones del repo y límites
    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
2026-09-16 diseño: sistema anti-slop (DESIGN.md formato estándar + VOICE.md) y aplicación
    - brand/DESIGN.md reescrito en formato tipo google-labs/design.md (tokens YAML +
    reglas + dials de taste-skill + anti-patterns de impeccable + lista negra)
    - brand/VOICE.md: guía de copy (Humanizer 25 reglas + Stop-Slop) en español
    - CLAUDE.md: enforce de diseño + voz en toda sesión
    - landing: aplicado — marcas de esquina y grilla de puntos solo en momentos
    firma (hero/nota/CTA), no en cada tarjeta (menos "plantilla")
    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
2026-09-16 landing: dirección "Editorial Locker Room" (lujo premium tipo Equinox/Third Space)
    - Rebuild del lenguaje: charcoal + bronce, tipografía oversized, mucho aire,
    filas editoriales en vez de cajas, reglas finas. Se sacó el sistema
    "instrumento técnico" (eyebrows §/ISSUE·/SEG·, grillas de puntos, marcas de
    esquina, nodos mono). 3D + marca + logo intactos.
    - brand/DESIGN.md: dials → editorial-luxury (varianza 7, densidad 3) +
    referencias reales (Equinox, Third Space, Barry's, vestuarios de lujo)
    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
2026-09-16 landing: 2 direcciones alternativas para comparar (Dark Room / Warm)
    - landing/variants/barrys.html — "Dark Room" (Barry's): negro dramático,
    tipografía mayúscula grande, glow del oro, energía club/gym
    - landing/variants/aesop.html — "Warm" (Aesop): crema cálido, serif editorial
    (Newsreader), mucho aire, calma; sin ticker
    Ambas reusan el motor 3D y la estructura de la landing editorial (v7).
    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
2026-09-16 fix(landing/warm): botones del CTA visibles + sin flecha "enter"
    - .cta-band en fondo claro: botones de tinta (no on-dark), antes quedaban
    crema sobre crema (invisibles)
    - quitada la flecha → de los botones (parecía un enter); botones más chicos/calmos
    - limpiado typo CSS de color
    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
2026-09-16 alineación total a "Warm" (Aesop): landing principal, panel y kit de redes
    - landing/index.html: ahora es la dirección Warm (crema + serif Newsreader),
    con el fix de botones del CTA
    - panel/index.html: reskin a cálido (crema, serif en títulos, oro muteado,
    sin grilla de puntos; estados legibles en claro)
    - marketing/redes/*: kit (10 placas) + reel transformados a crema + serif +
    oro profundo; reel con locker coherente
    - brand/DESIGN.md + CLAUDE.md: dirección activa = "warm-editorial" (ground claro,
    Newsreader), variantes oscuras quedan en landing/variants/
    Claude-Session: https://claude.ai/code/session_01AdUkgiVesmY5kdjwGs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
2026-09-16 Landing: aro LED de color + sacar OLED en todo el repo + placa Panel
    Landing (index + variantes aesop/barrys):
    - Saco los botones secundarios en blanco (hero y CTA band); dejo un solo CTA.
    - Justifico "Pedir demo" a la derecha también en mobile.
    - Rehago el indicador de estado 3D: un único aro LED que cambia de color
    suave (verde libre / ámbar reservado / azul ocupado), reposicionado lejos
    de la manija; saco el OLED, la tira LED inferior y el glow que titilaba.
    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
    [lockit_clear_gabinete.step, lockit_clear_modulo.step, lockit_clear_puerta.step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]
2026-09-16 Kit: placa Panel ajustada a 1080 (grilla de 10) + re-seed
    - Panel.dc.html: grilla de 10 lockers (2 filas) que entra completa en el
    artboard 1080×1080; métricas coherentes (Total 10 / Libres 6 / Ocupados 3).
    - Re-seed del canvas kit-redes-lockit.html con la placa corregida.
    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
